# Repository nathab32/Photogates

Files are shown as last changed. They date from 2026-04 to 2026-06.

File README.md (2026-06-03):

# Photogate

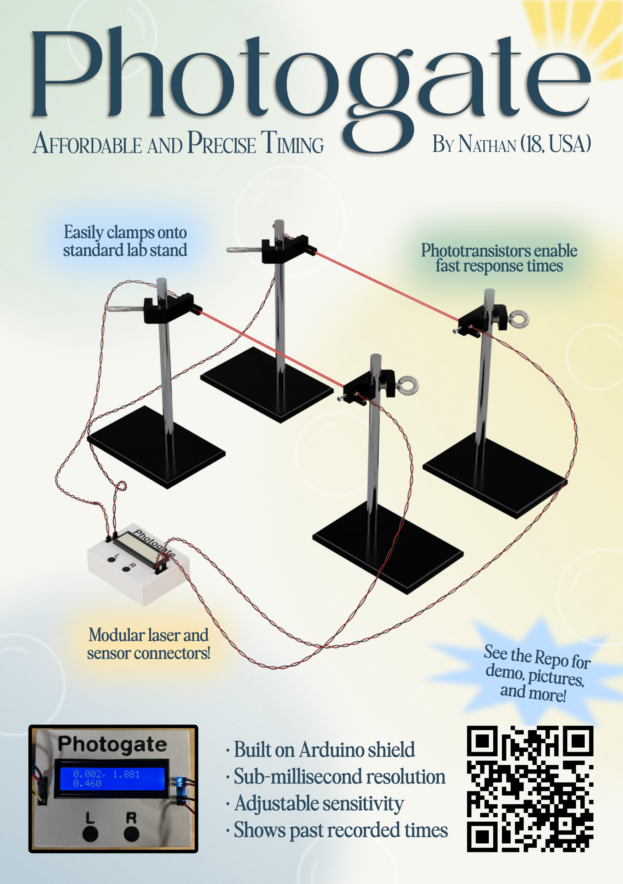
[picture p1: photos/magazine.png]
Magazine

[Video Demo](https://www.youtube.com/watch?v=dZhynI2hOx8)

## Description

Photogates allow precise, automatic timing of objects moving between two points. The photogates trigger automatically when a laser beam is interrupted, providing much faster response times than a human ever could with a stopwatch.

This specific project was inspired by my Science Olympiad team's lack of a photogate for the timing events. Commonly available solutions online cost at least $50, with high resolution ones costing hundreds of dollars. This design seeks to lower the barrier to precise timing by using commonly available parts and 3D printed materials for a cost-effective design. The design is fully open source to allow others to replicate and improve on it.

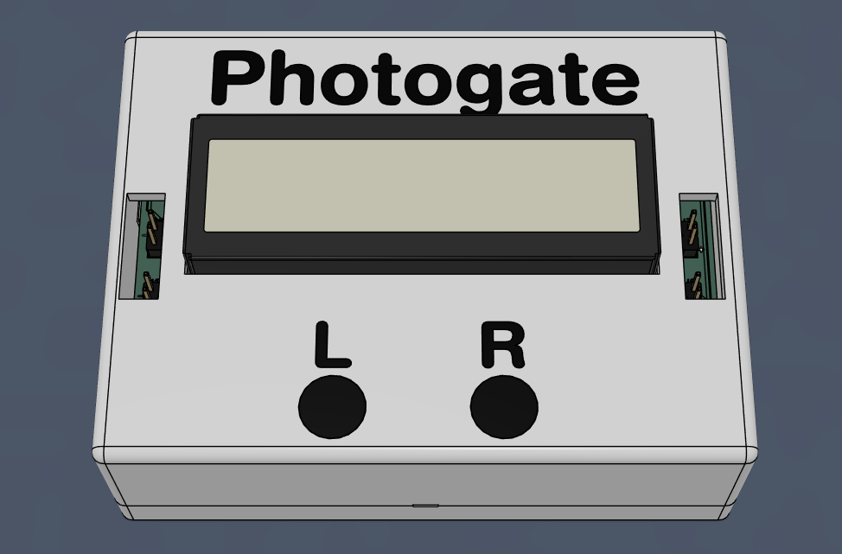
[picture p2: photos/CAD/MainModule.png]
Main Module Assembly

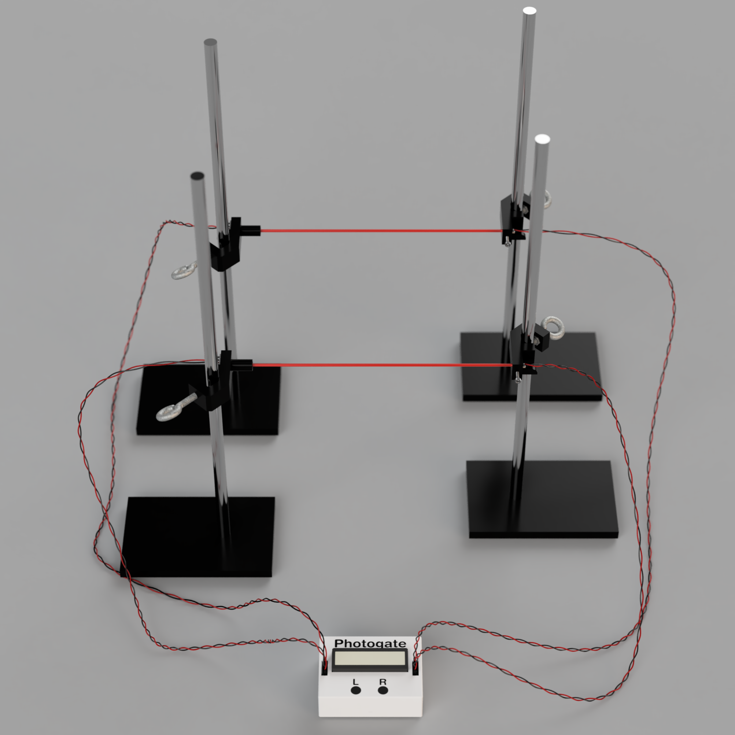
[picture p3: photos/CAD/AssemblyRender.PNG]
CAD Render


## Features

- Based on the Arduino UNO R3
- Swappable lasers and phototransistors
- Lasers and phototransistors mount to standard lab stands
- Displays last 3 recorded times
- Adjustable sensitivity
- Fully THT design
- Easy assembly

## Basic Usage

1. Position the two lasers perpendicular to the direction of travel at your specified distance.

2. Position the two phototransistors directly across from the two lasers. Each laser should hit straight onto a phototransistor.

3. Plug the lasers into the right side of the main module, and the phototransistors into the left side. The polarities are indicated on the silkscreen: a `+` for the lasers, and a `-` for the phototransistors.

4. When the module first powers on, calibration of the phototransistors will occur. The laser beams should be shining onto the phototransistors when this first occurs.

5. After calibration, make sure that the phototransistors are functioning by each beam independently. One of the interruptions should start the timing, indicated by `Timing...` on the LCD. The other interruption should stop the timing.
   - This is a good time to check the order of the phototransistors. If the order is incorrect, then simply plug the phototransistor in the top slot into the bottom slot and vice versa.

6. If everything has been executed correctly, then your photogate should be ready for timing! If you need to recalibrate at any point, simply press `R` again.

## Assembly

### 3D Printing

All 3D printing related files are included in the [`3D_Printing`](3D_Printing) directory. This includes the original `.f3d`, `.step`, and `.3mf` files.

If you don't use the `.3mf` file to slice, below are the parameters that I used.

|Parameter|Value|
|---|-----|
|Material|PLA|
|Layer Height|0.2mm|
|Nozzle|0.4mm|
|Infill|<20%|

The biggest issue I had was with printing the lettering due to some elephant's foot, but if you have a multicolor printer then this won't be an issue. Otherwise, you may need to play around with the letter offsets and/or printer settings to get the letters to fit. The lettering is also entirely visual, so you can skip it if you want.

### Lasers

1. Cut and strip the 2 strand wire to the necessary length.

2. Cut heat shrink to the necessary length. I used heat shrink with a diameter that allows it to grab onto the laser diode's PCB when flattened so some strain relief is provided to the wire.

3. Solder female headers to one end of the wire.

4. Remove the presoldered wire from the laser diode, taking note of which side of the resistor the negative wire was attached to.

5. Slip the heat shrink onto the 2 strand wire.

6. Solder the 2 strand wire to the laser diode. The negative wire should bypass the included resistor by soldering to the side that the original wire wasn't connected to. Otherwise, the current source circuit may not be able to drive the laser.
    - A multimeter in the diode mode can check which side of the resistor to solder to. The side of the resistor with a lower voltage reading bypasses the resistor.

7. Test the connection by plugging the headers onto the laser pins on the shield and powering it on.

8. If laser powers on, then use the heat shrink over the flat portion of the laser's PCB. Don't slide it over the metal cylindrical section, otherwise the laser won't fit into the 3D printed mount.

9. Slide the laser diode into the 3D print, and use a M3x10 set screw to hold it in place.

10. Place the nut into the 3D print, and screw the eye bolt in. You can optionally glue the nut in place, but I chose not to just so I can remove it later if necessary.

The finshed result should look something like this:
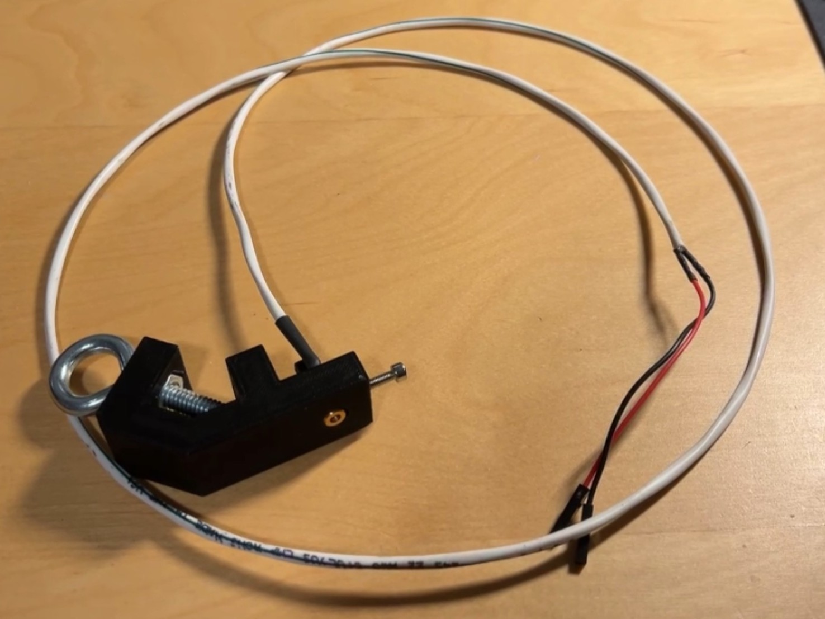
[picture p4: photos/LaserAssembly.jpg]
Laser Assembly


### Phototransistors

1. Score and cut a 1x6 section of copper plated perfboard. If your perfboard has one continous copper side, then remove a small line of copper the middle of the board, leaving connections from holes 1-3 and holes 4-6.

2. Drill the first and last holes in the perfboard with a 7/64" drill bit to allow a M2 screw through.

3. Cut and strip the 2 strand wire to the necessary length.

4. Solder female headers to one end of the wire.

5. Bend the phototransistor leads towards the flat side of the package approximately 2.5mm from the bottom of the package. The phototransistor should be able to sit inside of the recession in the 3D print and the leads should stick through the 3rd and 4th holes of the perfboard.

6. With the phototransistor inside the recession, screw the perfboard to the 3D print using 2 M2x4 screws with the copper side facing out.

7. Solder the phototransistor to the perfboard, careful not to let the two sides short out.

8. Solder the 2 strand wire to the two remaining holes in the perfboard. With the phototransistor pointing down, the collector/positive is the right hole, and the emitter/negative is the left hole.

9. Test the connection by measuring the "resistance" of the phototransistor. With the positive lead connected to the collecter and negative lead connected to the emitter, the resistance should start high and go lower when exposed to light. When the leads are switched, the resistance is always high or open.

10. Place the nut into the 3D print, and screw the eye bolt in. You can optionally glue the nut in place, but I chose not to just so I can remove it later if necessary.

11. With a small strip of black electrical tape, cover the back side of the phototransistor to stop ambient light from hitting the sensor.

12. Glue the 3D printed cylinder to the mount, making sure that it sits perpendicular to the front face of the mount and doesn't interfere with the path of light.

The finshed result should look something like this:
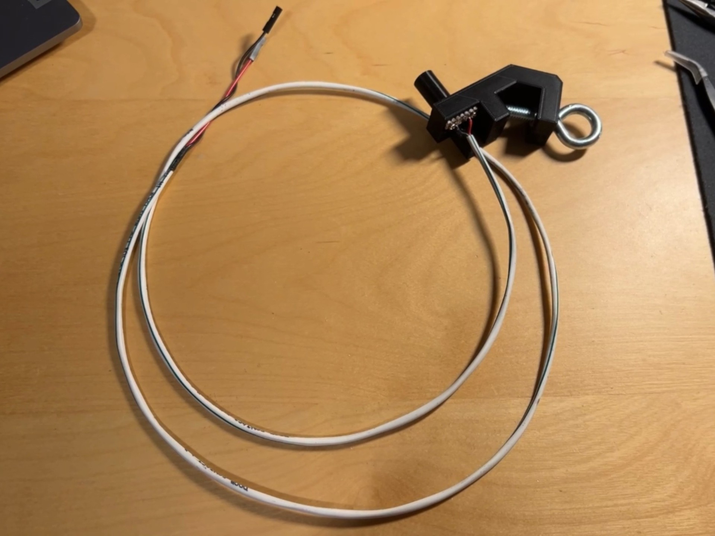
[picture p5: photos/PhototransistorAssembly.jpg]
Phototransistor Assembly

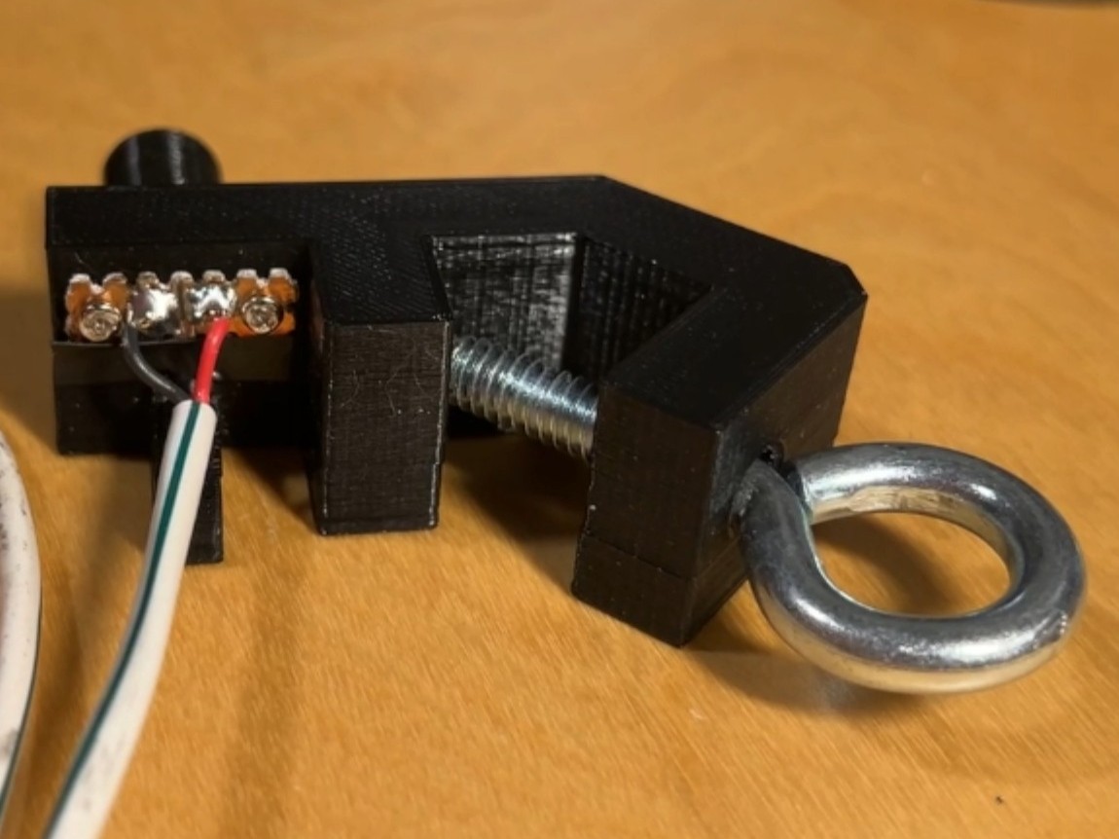
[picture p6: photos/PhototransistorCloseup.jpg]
Phototransistor Closeup


### Shield

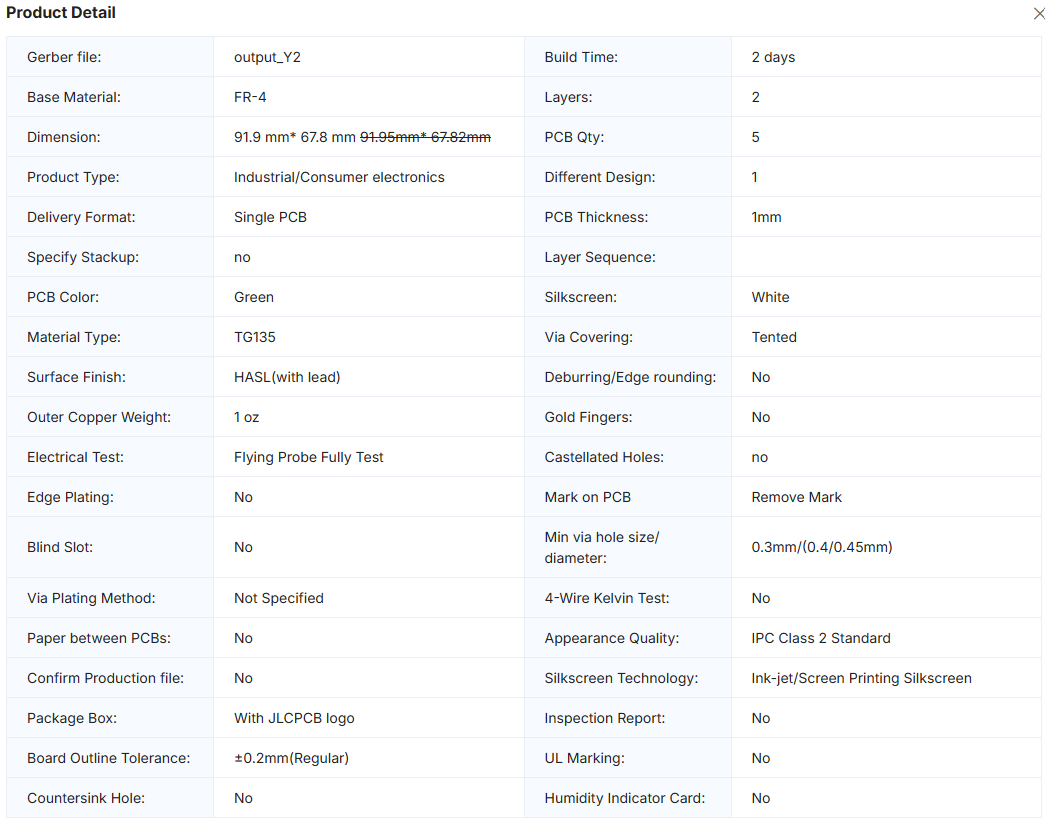
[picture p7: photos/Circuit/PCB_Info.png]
PCB Ordering
1. Order a PCB from your desired PCB manufacturer (I used JLCPCB) with the included [Gerbers](PCB/Gerber.zip). Refer to the following image for the ordering info: 

2. Using the included [KiCad project](PCB/KiCad.zip), solder the components to their respective places on the PCB. Everything is throughhole and can be soldered by hand, but be especially careful while soldering the transistors since the pitch is quite small. The schematics and PCB can also be viewed in [`photos/Circuit`](photos/Circuit).

### Final Assembly

1. Screw the Arduino UNO R3 onto the bottom plate with 4x M3x6 screws.

2. Firmly push the shield onto the top of the UNO, making sure that all header pins line up.

3. Place the top cover over the shield, and firmly push down until the cover snaps into place.

4. Glue the lettering and buttons into place.
   - Make sure not to test the fit for the buttons (with the cover on as well) before gluing. When gluing, make sure not to put too much that it clogs up the button.

5. Upload the code by cloning this repository and opening the folder in PlatformIO. Simply plug in the Arduino to your computer, go to [main.cpp](src/main.cpp), and hit the arrow in the top right corner (Ctrl+Alt+U) and wait for the success message.

6. Test that everything works by going to [Basic Usage](#basic-usage)

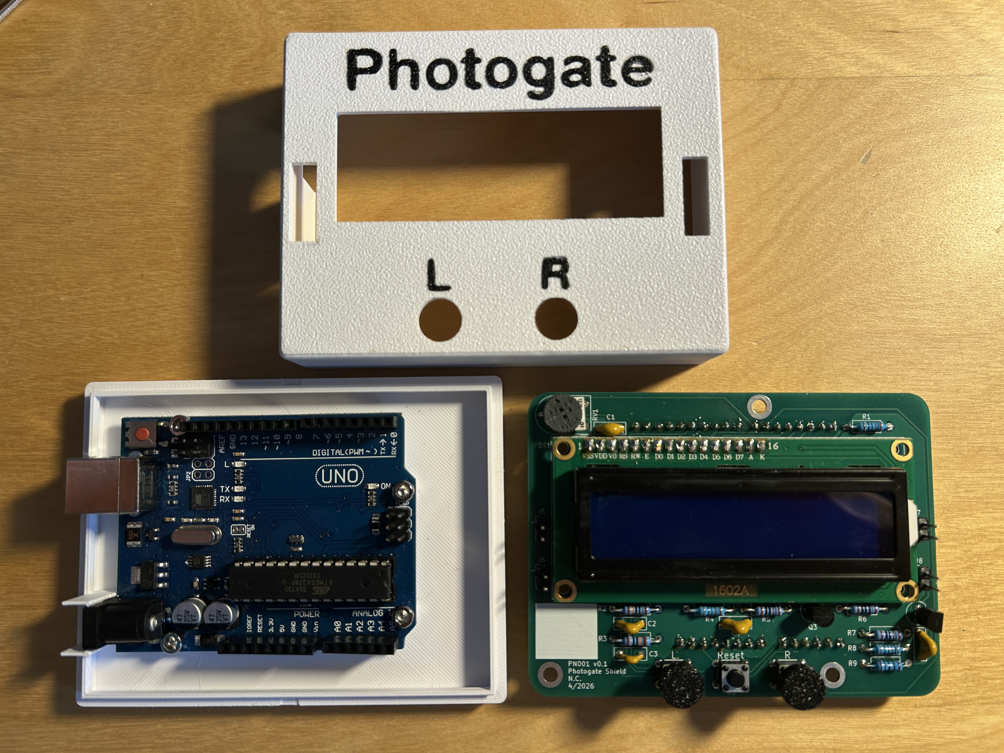
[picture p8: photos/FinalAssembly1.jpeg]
All parts before final assembly

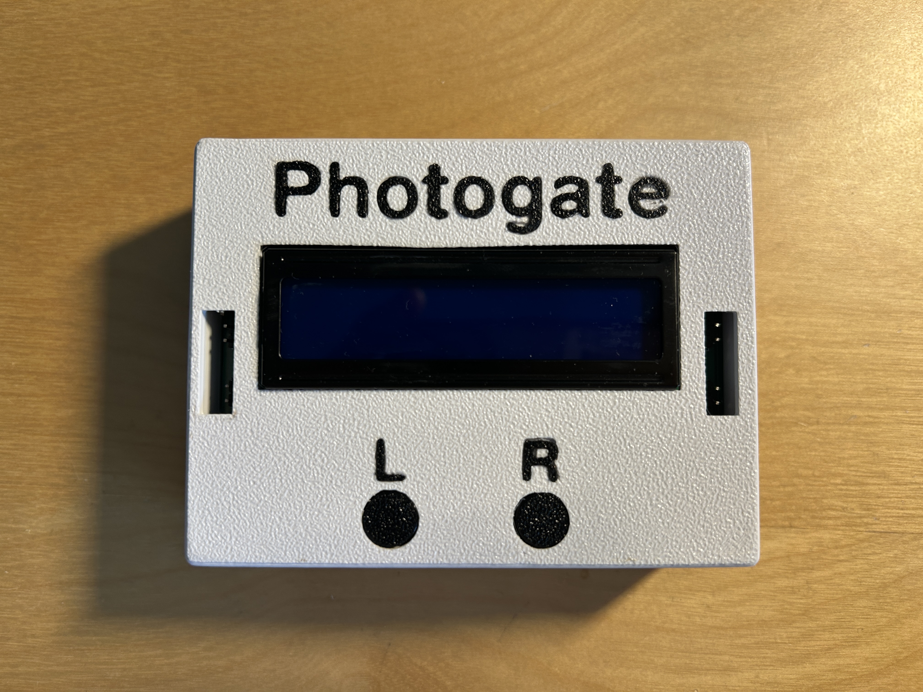
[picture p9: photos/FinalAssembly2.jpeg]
Final assembly


## BOM

The BOM can be viewed in [`BOM.csv`](BOM.csv)

## Todo

- distance input for avg speed
- switch phototransistor 0 and 1 (automatically?)
- single laser mode
- Output data to serial
- New board: control laser on/off with arduino

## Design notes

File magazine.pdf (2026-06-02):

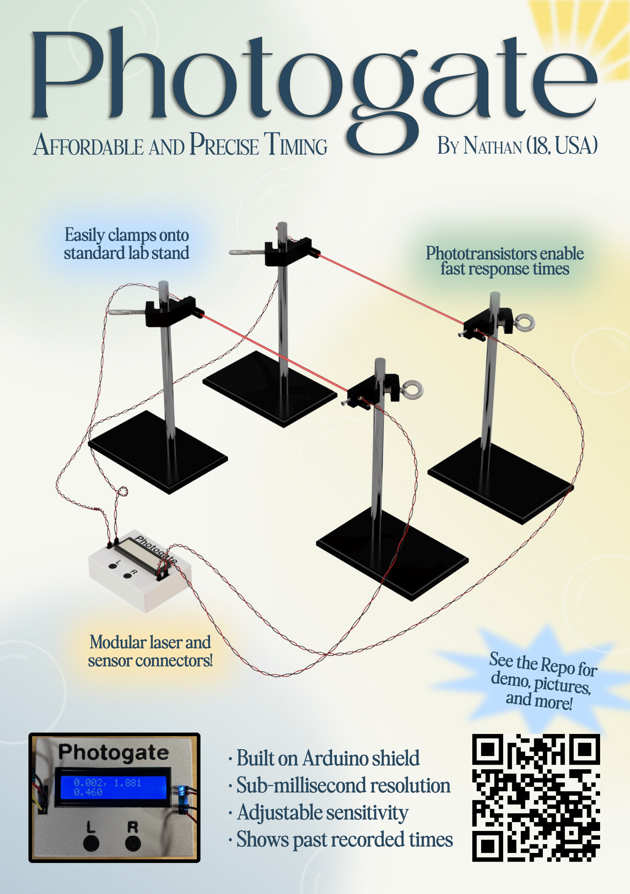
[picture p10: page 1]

Photogate AFFORDABLE AND PRECISE TIMING | BY NATHAN (18, USA)

See the Repo for
demo, pictures,
and more!

Modular laser and
sensor connectors!

Easily clamps onto
standard lab stand | Phototransistors enable fast response times
- Built on Arduino shield
- Sub-millisecond resolution
- Adjustable sensitivity
- Shows past recorded times

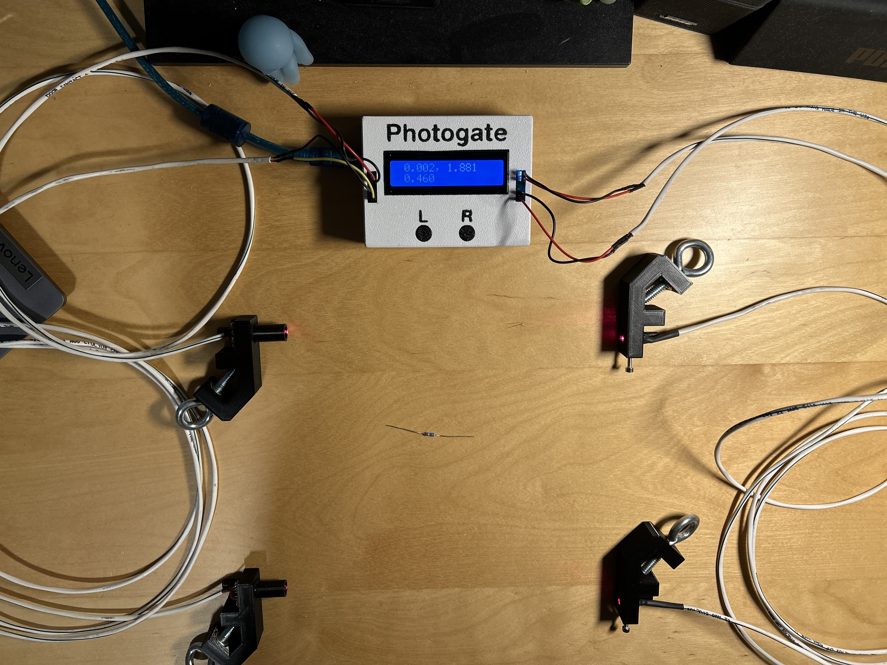
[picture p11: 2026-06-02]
photos/builtDevice/overview.jpeg

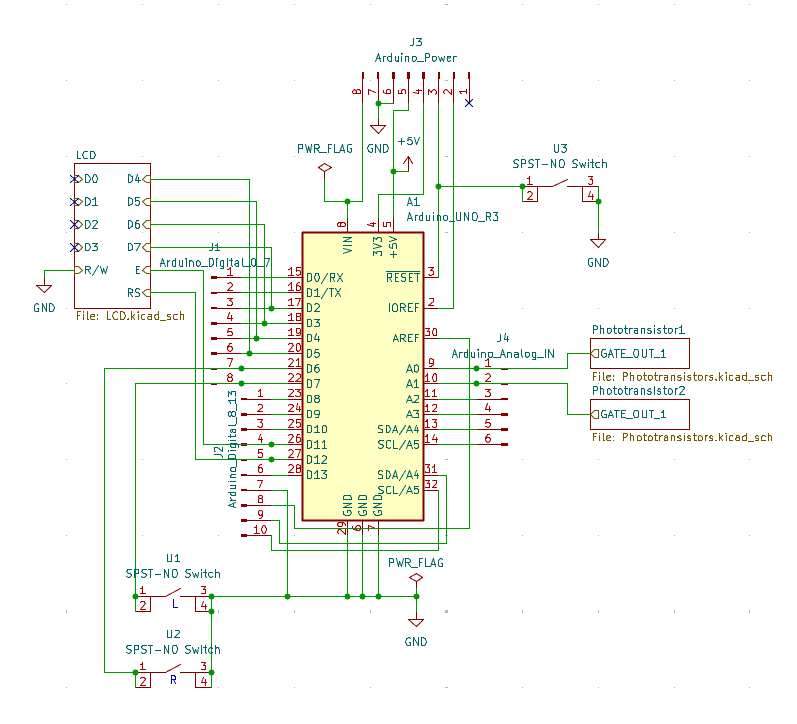
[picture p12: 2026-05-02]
photos/Circuit/main.png

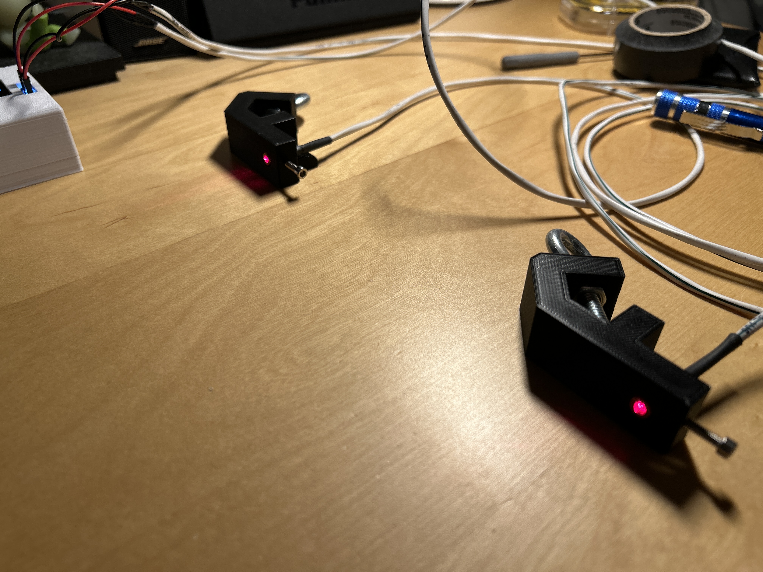
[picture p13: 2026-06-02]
photos/builtDevice/lasers.jpeg

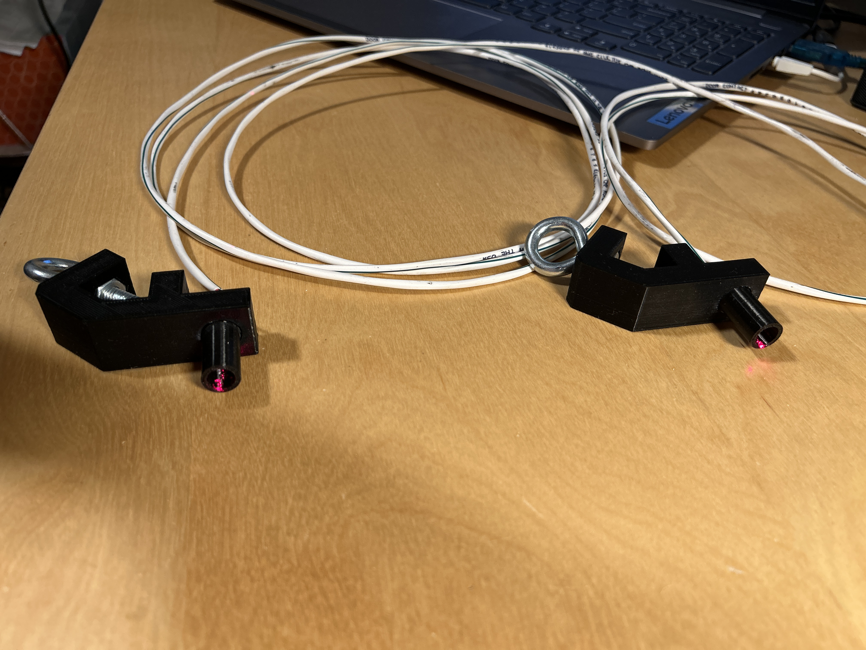
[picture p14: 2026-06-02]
photos/builtDevice/phototransistors.jpeg

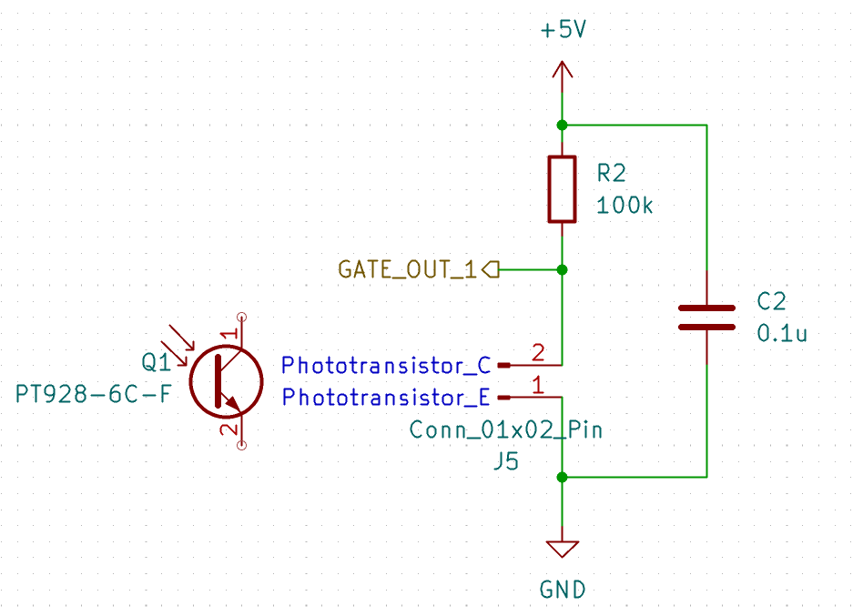
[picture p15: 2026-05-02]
photos/Circuit/Phototransistor.png

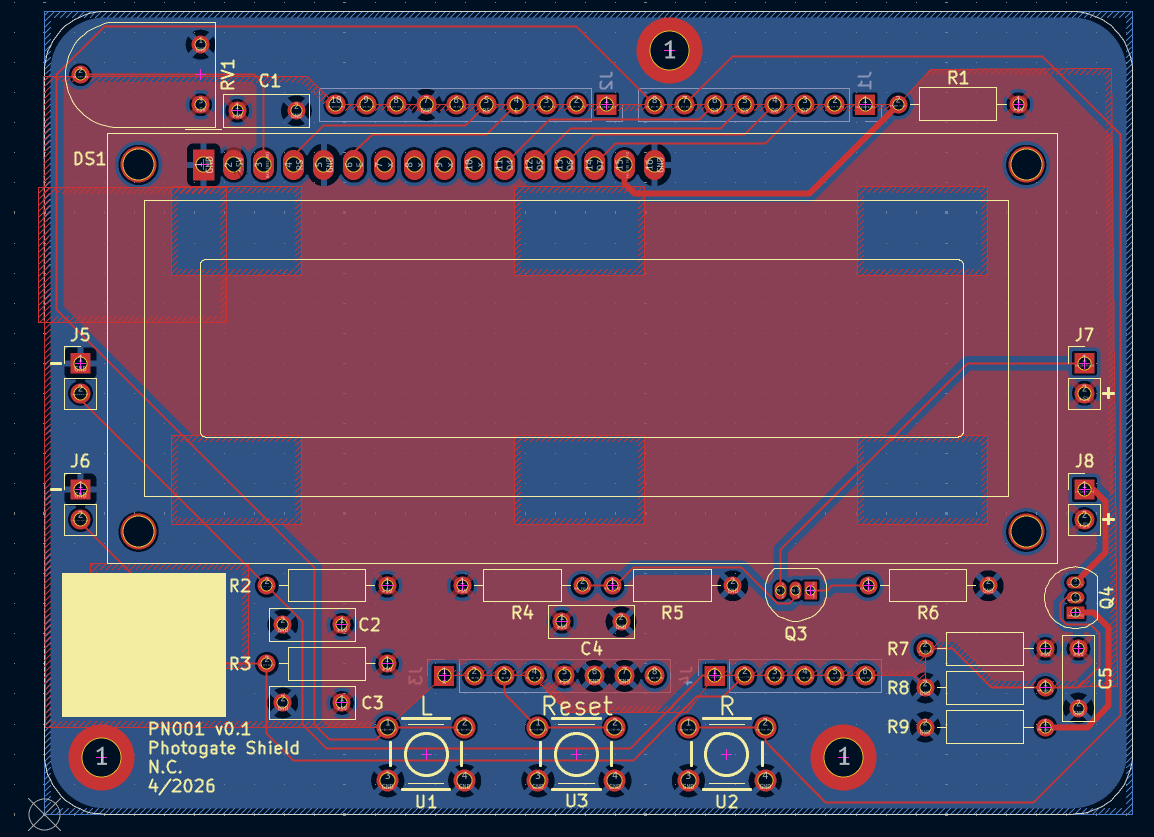
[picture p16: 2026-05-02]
photos/Circuit/PCB.png

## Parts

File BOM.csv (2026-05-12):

Electronics |  |  |  |  |  |  |  | Mechanical
# | Qty | Reference | Value | Description | Link | Price/unit | Total Price | # | Qty | Item | Link | Price/unit | Total Price
1 | 1 | A1 | Arduino_UNO_R3 | Arduino UNO R3 | https://a.co/d/0gtx5tss | $7.99 | $7.99 | 1 | 4 | M3x6 screw | https://a.co/d/0aZcBFy4 | $0.01 | $0.05
2 | 1 | C1 | 1u | Ceramic capacitor | https://a.co/d/00MB8bSj | $0.02 | $0.02 | 2 | 2 | M3x10 screw | https://a.co/d/0aZcBFy4 | $0.01 | $0.02
3 | 4 | C2,C3,C4,C5 | 0.1u | Ceramic capacitor | https://a.co/d/00MB8bSj | $0.02 | $0.09 | 3 | 4 | M2x4 screw | https://a.co/d/0aZcBFy4 | $0.01 | $0.05
4 | 1 | DS1 | WC1602A | LCD 16x2 Alphanumeric , 8 bit parallel bus, 5V VDD | https://a.co/d/0a6xKTI6 | $5.00 | $5.00 | 4 | 2 | 1/4x2" Eye Bolt w/ Nut, 2 pack | https://www.homedepot.com/p/Everbilt-1-4-in-20-x-2-in-Zinc-Eye-Bolt-2-Pack-824301/314745414 | $1.57 | $3.14
5 | 1 | J1 | Arduino_Digital_0_7 | 01x08 2.54mm Pin Headers | https://a.co/d/0f7wE6Ru | $0.08 | $0.08 | 5 | 2 | Laser Mount | See attached .f3d, .step, or .3mf file | $0.17 | $0.34
6 | 1 | J2 | Arduino_Digital_8_13 | 01x10 2.54mm Pin Headers | https://a.co/d/0f7wE6Ru |  | $- | 6 | 2 | Phototransistor Mount | See attached .f3d, .step, or .3mf file | $0.17 | $0.34
7 | 1 | J3 | Arduino_Power | 01x08 2.54mm Pin Headers | https://a.co/d/0f7wE6Ru |  | $- | 7 | 2 | Light Cover | See attached .f3d, .step, or .3mf file | $0.02 | $0.04
8 | 1 | J4 | Arduino_Analog_IN | 01x06 2.54mm Pin Headers | https://a.co/d/0f7wE6Ru |  | $- | 8 | 1 | Bottom Case | See attached .f3d, .step, or .3mf file | $0.36 | $0.36
9 | 4 | J5,J6,J7,J8 | Conn_01x02_Pin | 01x02 2.54mm Pin Headers | https://a.co/d/0f7wE6Ru |  | $- | 9 | 1 | Top Case | See attached .f3d, .step, or .3mf file | $0.47 | $0.47
10 | 2 | LD1,LD2 | LASER-650NM | 5mW Laser Diode | https://a.co/d/0iFaSl0f | $0.68 | $1.36 | 10 | 1 | Buttons | See attached .f3d, .step, or .3mf file | $0.01 | $0.01
11 | 2 | Q1,Q2 | PT928-6C-F | NPN phototransistor, collector/emitter | https://www.digikey.com/short/hrb7dw75 | $0.37 | $0.74 | 11 | 1 | Text | See attached .f3d, .step, or .3mf file | $0.01 | $0.01
12 | 2 | Q3,Q4 | 2N3904 | 0.2A Ic, 40V Vce, Small Signal NPN Transistor, TO-92 | https://a.co/d/05KZVKDI | $0.04 | $0.08 |  |  |  |  |  | $4.82
13 | 1 | R1 | 220 | 1/4W 1% Metal Film Resistor | https://a.co/d/0gNADgIb | $0.02 | $0.02
14 | 2 | R2,R3 | 100k | 1/4W 1% Metal Film Resistor | https://a.co/d/0gNADgIb | $0.02 | $0.03
15 | 4 | R4,R5,R7,R8 | 1k | 1/4W 1% Metal Film Resistor | https://a.co/d/0gNADgIb | $0.02 | $0.06
16 | 2 | R6,R9 | 100 | 1/4W 1% Metal Film Resistor | https://a.co/d/0gNADgIb | $0.02 | $0.03
17 | 1 | RV1 | 10k | Potentiometer | https://www.digikey.com/short/5dwzm9ph | $3.34 | $3.34
18 | 3 | U1,U2,U3 | SPST-NO Switch | 6mm x 6mm Tactile Switch | https://www.digikey.com/short/5j295w20 | $0.13 | $0.39
19 | 1 | N/A | N/A | Stranded twisted pair, 24AWG | https://a.co/d/0jb6LYgm | $3.19 | $3.19
20 | 4 | N/A | N/A | Female to Female dupont wires for soldering | https://a.co/d/081eLbjy | $0.06 | $0.23
21 | 1 | N/A | N/A | PCB | See attached KiCad/Gerbers | $2.00 | $2.00
 |  |  |  |  |  |  | $22.64
 |  |  |  |  |  | Subtotal: | $27.47
 |  |  |  |  |  | Shipping: | $5.00
 |  |  |  |  |  | PCB: | $5.00
 |  |  |  |  |  | Tax: | $1.87
 |  |  |  |  |  | Total: | $39.34

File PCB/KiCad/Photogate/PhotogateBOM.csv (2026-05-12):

# | Qty | Reference | Value | Description
1 | 1 | A1 | Arduino_UNO_R3 | Arduino UNO Microcontroller Module, release 3
2 | 1 | C1 | 1u | Unpolarized capacitor
3 | 4 | C2,C3,C4,C5 | 0.1u | Unpolarized capacitor
4 | 1 | DS1 | WC1602A | LCD 16x2 Alphanumeric , 8 bit parallel bus, 5V VDD
5 | 1 | J1 | Arduino_Digital_0_7 | 01x08 2.54mm Pin Headers
6 | 1 | J2 | Arduino_Digital_8_13 | 01x10 2.54mm Pin Headers
7 | 1 | J3 | Arduino_Power | 01x08 2.54mm Pin Headers
8 | 1 | J4 | Arduino_Analog_IN | 01x06 2.54mm Pin Headers
9 | 4 | J5,J6,J7,J8 | Conn_01x02_Pin | 01x02 2.54mm Pin Headers
10 | 2 | LD1,LD2 | LASER-650NM | Laser diode, cathode on pin 1, anode on pin 2
11 | 2 | Q1,Q2 | PT928-6C-F | NPN phototransistor, collector/emitter
12 | 2 | Q3,Q4 | 2N3904 | 0.2A Ic, 40V Vce, Small Signal NPN Transistor, TO-92
13 | 1 | R1 | 220 | Resistor
14 | 2 | R2,R3 | 100k | Resistor
15 | 4 | R4,R5,R7,R8 | 1k | Resistor
16 | 2 | R6,R9 | 100 | Resistor
17 | 1 | RV1 | 10k | Potentiometer
18 | 3 | U1,U2,U3 | SPST-NO Switch | 6mm x 6mm Tactile Switch

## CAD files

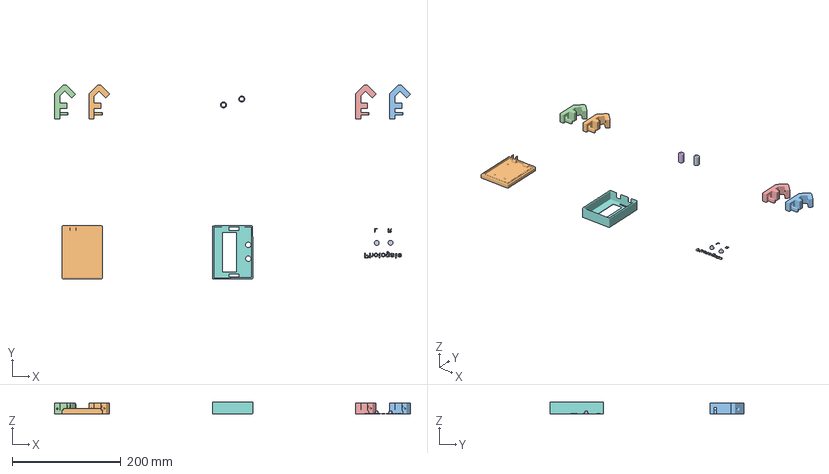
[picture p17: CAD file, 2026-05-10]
3D_Printing/Photogate.3mf
653.3 x 356.6 x 22.5 mm
Photoresistor Mount v1-SOLID-2 x 2
Laser Mount.step x 2
Phototransistor Mount v1-SOLID-1 x 2
Text.step
Case-SOLID-1
Buttons.step
Case-SOLID-2

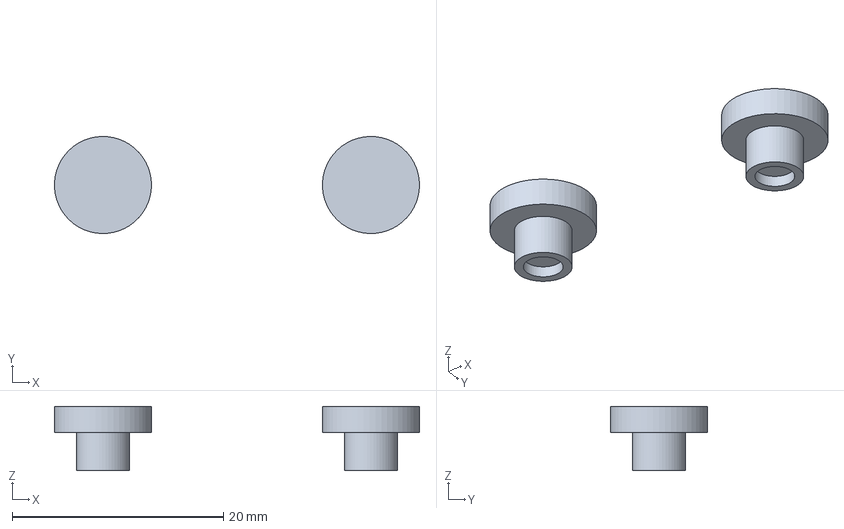
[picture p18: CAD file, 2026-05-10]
3D_Printing/step/Buttons.step
34.6 x 9.20 x 6.10 mm

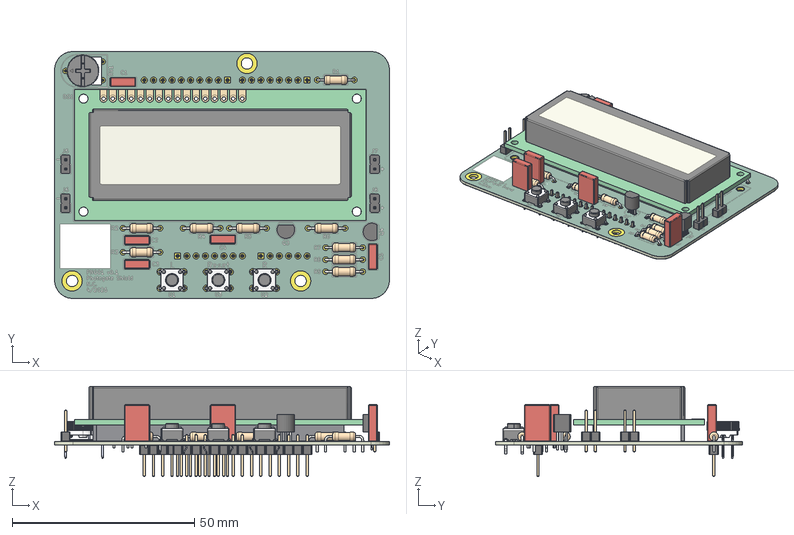
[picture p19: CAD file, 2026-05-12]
PCB/KiCad/Photogate/Photogate.step
91.9 x 67.8 x 24.7 mm
SW-TH_4P-L6.0-W6.0-H5.0-LS6.5-P4.50 x 3
C_Rect_L7.0mm_W2.5mm_P5.00mm x 5
R_Axial_DIN0207_L6.3mm_D2.5mm_P10.16mm_Horizontal x 9
TO-92_Inline x 2
PinHeader_1x02_P2.54mm_Vertical x 4
3352E-1-103LF
WC1602A
PinHeader_1x08_P2.54mm_Vertical x 2
PinHeader_1x06_P2.54mm_Vertical
PinHeader_1x10_P2.54mm_Vertical
Photogate_copper
Photogate_silkscreen x 2
Photogate_soldermask x 2
Photogate_PCB

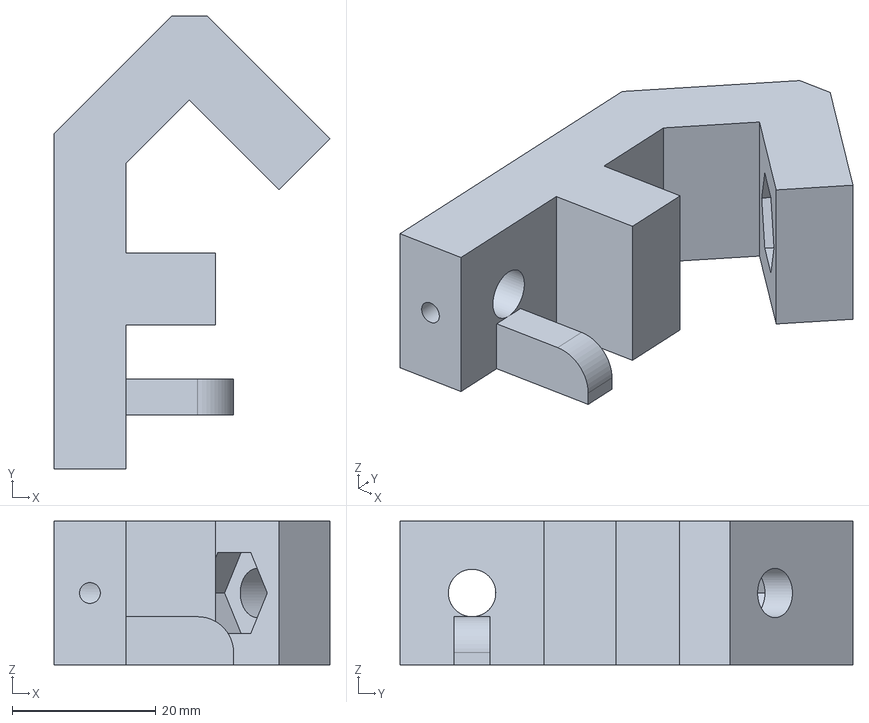
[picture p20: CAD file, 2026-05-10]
3D_Printing/step/Laser Mount v7.step
38.4 x 63.0 x 20.0 mm

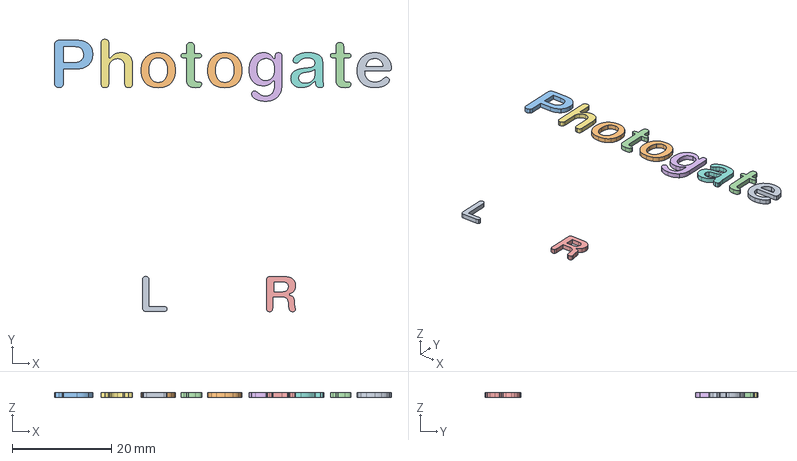
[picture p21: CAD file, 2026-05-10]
3D_Printing/step/Text.step
67.8 x 54.9 x 1.00 mm

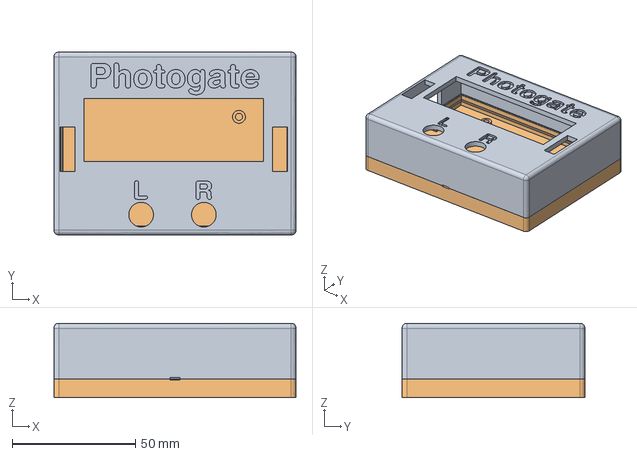
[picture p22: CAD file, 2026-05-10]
3D_Printing/step/Case.step
98.0 x 74.0 x 30.1 mm

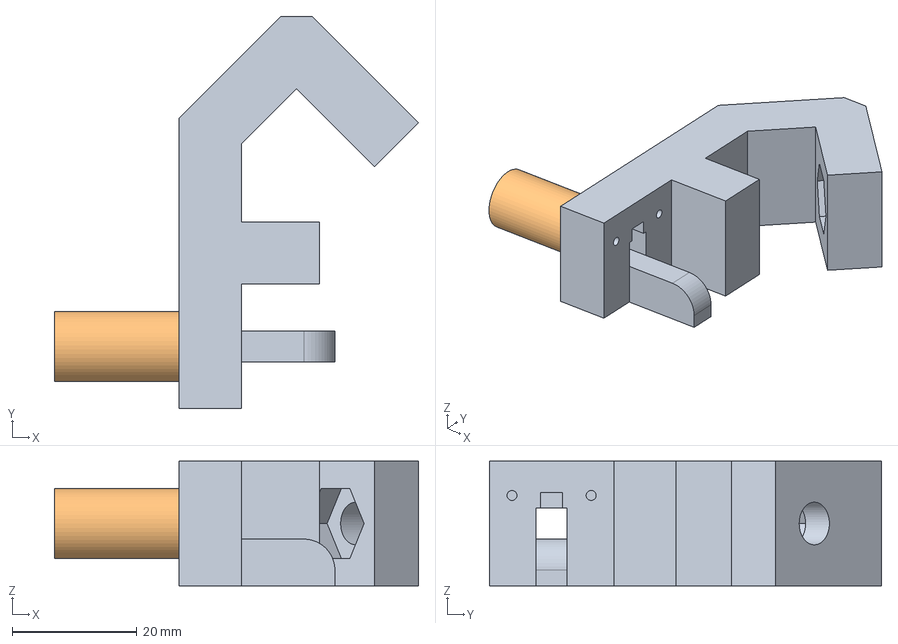
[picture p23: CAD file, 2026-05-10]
3D_Printing/step/Phototransistor Mount v7.step
58.4 x 63.0 x 20.0 mm

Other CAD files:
3D_Printing/fusion/Buttons.f3d
3D_Printing/fusion/Case.f3d
3D_Printing/fusion/Laser Mount.f3z
3D_Printing/fusion/Phototransistor Mount.f3z
3D_Printing/fusion/Text.f3d

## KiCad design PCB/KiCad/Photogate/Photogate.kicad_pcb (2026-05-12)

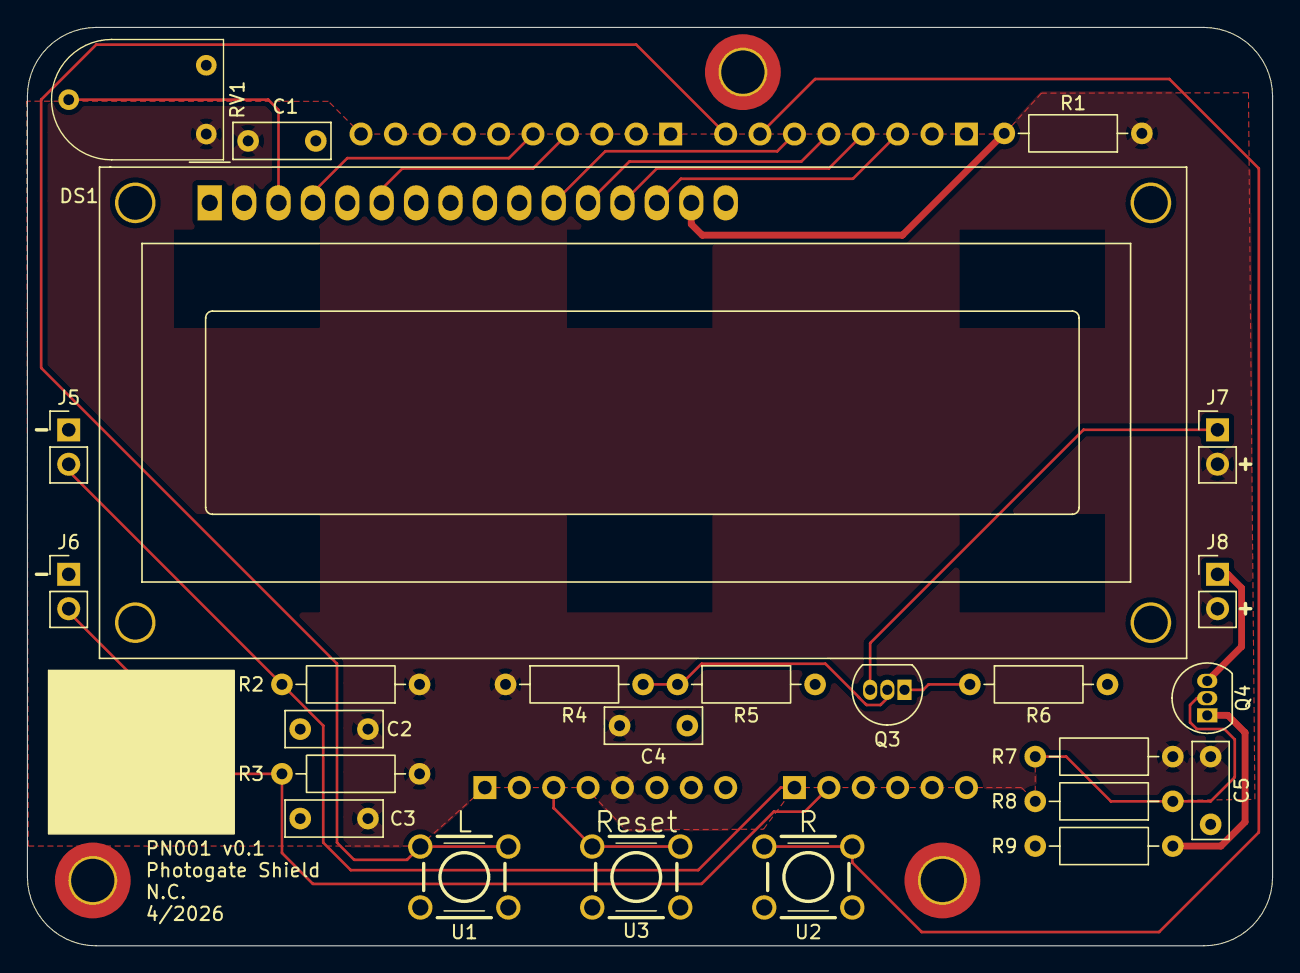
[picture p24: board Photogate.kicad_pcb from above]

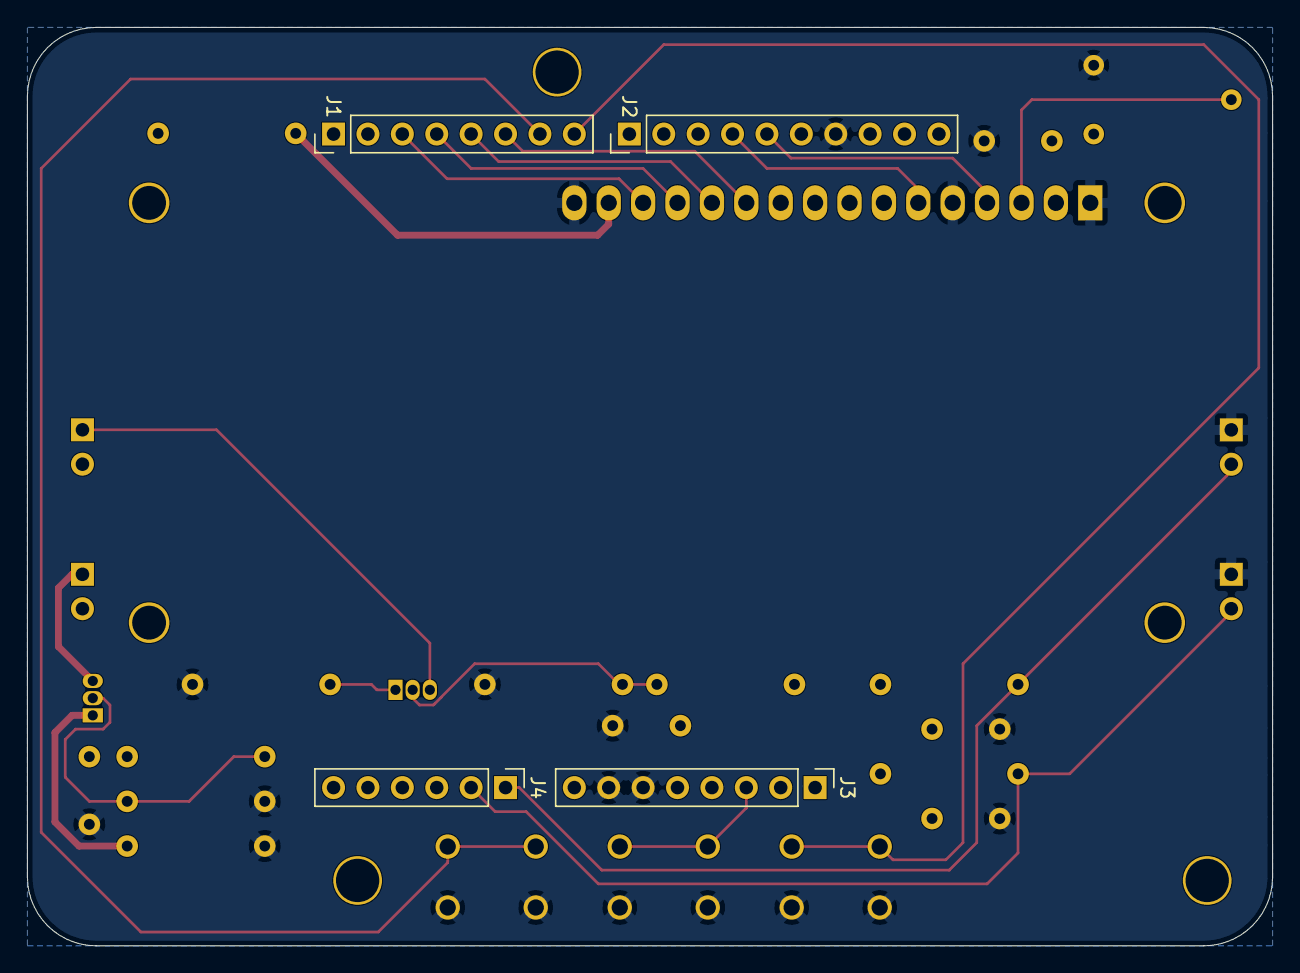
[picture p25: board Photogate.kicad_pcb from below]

Board: 2 copper layers, 91.9 x 67.8 mm, 29 parts (4 on the bottom side), 21 nets.

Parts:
C1: 1u; C_Rect_L7.0mm_W2.5mm_P5.00mm
C2, C3, C4, C5: 0.1u; C_Rect_L7.0mm_W2.5mm_P5.00mm
DS1: WC1602A
J1: Arduino_Digital_0_7; PinHeader_1x08_P2.54mm_Vertical
J2: Arduino_Digital_8_13; PinHeader_1x10_P2.54mm_Vertical
J3: Arduino_Power; PinHeader_1x08_P2.54mm_Vertical
J4: Arduino_Analog_IN; PinHeader_1x06_P2.54mm_Vertical
J5, J6, J7, J8: Conn_01x02_Pin; PinHeader_1x02_P2.54mm_Vertical
Q3, Q4: 2N3904; TO-92_Inline
R1: 220; R_Axial_DIN0207_L6.3mm_D2.5mm_P10.16mm_Horizontal
R2, R3: 100k; R_Axial_DIN0207_L6.3mm_D2.5mm_P10.16mm_Horizontal
R4, R5, R7, R8: 1k; R_Axial_DIN0207_L6.3mm_D2.5mm_P10.16mm_Horizontal
R6, R9: 100; R_Axial_DIN0207_L6.3mm_D2.5mm_P10.16mm_Horizontal
RV1: 10k; Bourns_3352E
U1, U2, U3: SPST-NO Switch; SW-TH_4P-L6.0-W6.0-P4.50-LS6.5

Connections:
+5V: C1.1, C2.1, C3.1, C4.1, C5.1, DS1.2 (VDD), J3.5, J7.2, J8.2, R1.1, R2.1, R3.1, R4.1, R7.1, RV1.3
/LCD/D4: DS1.11 (D4), J1.6
/LCD/D5: DS1.12 (D5), J1.5
/LCD/D6: DS1.13 (D6), J1.4
/LCD/D7: DS1.14 (D7), J1.3
/LCD/E: DS1.6 (E), J2.4
/LCD/RS: DS1.4 (RS), J2.5
/Phototransistor1/GATE_OUT_1: J4.1, J5.2, R2.2
/Phototransistor2/GATE_OUT_1: J4.2, J6.2, R3.2
GND: C1.2, C2.2, C3.2, C4.2, C5.2, DS1.1 (VSS), DS1.5 (R/W), DS1.16 (LED(-)), J2.7, J3.6, J3.7, J5.1, J6.1, R5.2, R6.2, R8.2, R9.2, RV1.1, U1.3, U1.4, U2.3, U2.4, U3.3, U3.4
unnamed: DS1.15 (LED(+)), R1.2
unnamed: DS1.3 (VO), RV1.2
unnamed: J1.7, U2.1, U2.2
unnamed: J1.8, U1.1, U1.2
unnamed: J3.3, U3.1, U3.2
unnamed: J7.1, Q3.3 (C)
unnamed: J8.1, Q4.3 (C)
unnamed: Q3.2 (B), R4.2, R5.1
unnamed: Q3.1 (E), R6.1
unnamed: Q4.2 (B), R7.2, R8.1
unnamed: Q4.1 (E), R9.1

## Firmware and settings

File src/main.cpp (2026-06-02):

#include <Arduino.h>
#include <LiquidCrystal.h>
#include <Wire.h>
#include <Button.h>

#define version "v0.1"

Button right(6, 50, 1000);
Button left(7, 50, 1000);

LiquidCrystal lcd(12, 11, 5, 4, 3, 2);
const int photo0 = 0;
const int photo1 = 1;

//calibrate when phototransistors are unlit to get full scale value
double sensitivity = 10.0;
int threshold0, threshold1;
unsigned long initialTime;
bool timing = false;
bool timeRecorded = false;

const int length = 3;
float times[length];

void resetSensitivity(){
  threshold0 = (int)((20/sensitivity) + analogRead(photo0));
  threshold1 = (int)((20/sensitivity) + analogRead(photo1));
  Serial.print("sensitivity reset, threshold0: ");
  Serial.print(threshold0);
  Serial.print(", threshold1: ");
  Serial.println(threshold1);

  lcd.setCursor(7, 1);
  lcd.print("Sens rst.");
}

float* updateTimes(float* array, float newTime){
  
  for (int i = length-2; i >= 0; i--) {
    array[i + 1] = array[i];
  }
  array[0] = newTime;

  // char buffer[50];
  // sprintf(buffer, "[%lu, %lu, %lu]", times[0], times[1], times[2]);
  // Serial.println(buffer);
  return array;
}

void updateLCD(){
  lcd.clear();

  char buffer1[50];
  char floatBuffer1[10], floatBuffer2[10], floatBuffer3[10];

  dtostrf(times[0], 6, 3, floatBuffer1);
  dtostrf(times[1], 6, 3, floatBuffer2);
  dtostrf(times[2], 6, 3, floatBuffer3);

  snprintf(buffer1, sizeof(buffer1), "%s,%s", floatBuffer1, floatBuffer2);

  Serial.println(buffer1);
  Serial.println(floatBuffer3);

  lcd.print(buffer1);
  lcd.setCursor(0, 1);
  lcd.print(floatBuffer3);
}

void setup() {
  Serial.begin(115200);
  lcd.begin(16, 2);
  lcd.print("Photogate");
  lcd.setCursor(0, 1);
  lcd.print(version);
  delay(1000);
  lcd.clear();
  lcd.print("Calibrating...");
  delay(1000);
  threshold0 = (int)((20/sensitivity) + analogRead(photo0));
  threshold1 = (int)((20/sensitivity) + analogRead(photo1));

  lcd.clear();
  updateLCD();

  right.pressFunction(resetSensitivity);
}

void loop() {
  right.handle();

  // Serial.println(">base:0");
  // Serial.println(">peak:5");
  Serial.print(">photo0: ");
  Serial.println(analogRead(photo0));
  Serial.print(">photo1: ");
  Serial.println(analogRead(photo1));
  Serial.print(">threshold0: ");
  Serial.println(threshold0);
  Serial.print(">threshold1: ");
  Serial.println(threshold1);

  if(!timing && (analogRead(photo0) > threshold0)){
    timing = true;
    initialTime = micros();
    Serial.println("Timing...");

    lcd.setCursor(7, 1);
    lcd.print("Timing...");
  }

  if(timing){

    if(!timeRecorded && (analogRead(photo1) > threshold1)){
      Serial.println("timed");
      updateTimes(times, (micros() - initialTime)/1000000.0);
      updateLCD();
      timeRecorded = true;
    }

    if(timeRecorded && (analogRead(photo1) < threshold1)){
      timing = false;
      timeRecorded = false;
    }
  }

  
}

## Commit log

2026-04-23 Fixed issue with blocking code, while still fixing the issue of triggering over and over the photogate when both beams are interrupted. Also changed threshold to an int and only calculate when necess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
    [main.cpp]
2026-04-30 Add photos of laser and phototransistor examples
2026-04-30 Add images, finish text of assembly section
2026-05-02 Upload BOM
    [BOM.csv]
2026-05-02 Add .step files for the laser and phototransistor mounts
    [LaserMount.step, PhototransistorMount.step]
2026-05-02 remove extra column
    [BOM.csv]
2026-05-02 Add images of circuits/cad
2026-05-07 Added step and fusion files for 3D printing
    [Buttons.f3d, Buttons.step, Case.f3d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]
2026-05-10 add extra costs
    [BOM.csv]
2026-05-10 Reupload 3d printing files, add assembly + 3mf
    [Buttons.f3d, Buttons.step, Case.f3d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]
2026-05-12 Add kicad+manufacturing files
2026-05-12 Add PCB ordering instructions and related image to README
2026-05-12 Add KiCAD files
    [LCD.kicad_sch, Laser.kicad_sch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]
2026-05-12 fix links
    [BOM.csv]
2026-05-25 Move assembly file and add step assembly
2026-05-25 Add picture of PCB in cad
2026-06-02 Update readme to reflect calibration procedure
2026-06-02 change threshold calculation in resetSensitivity()
    [main.cpp]
2026-06-02 images of built device
